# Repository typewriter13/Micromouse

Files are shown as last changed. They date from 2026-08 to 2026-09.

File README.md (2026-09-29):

# Micromouse

MicroMouse is a small autonomous robot designed to navigate and solve a maze completely on its own.
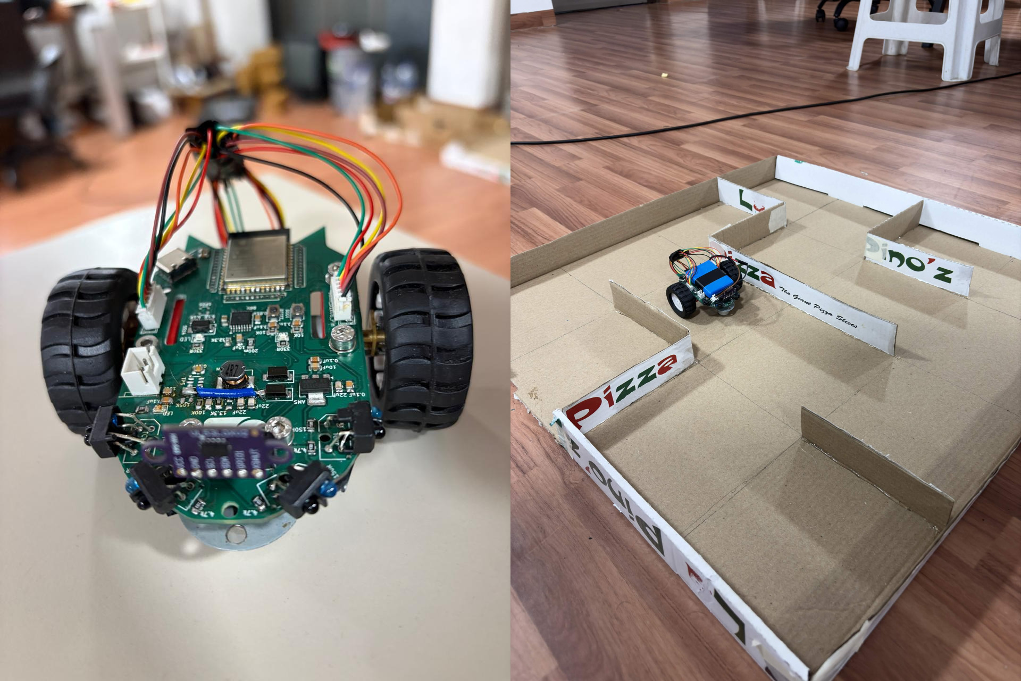
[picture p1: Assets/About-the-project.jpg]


## About The Project

Our project is about a wall-following micromouse robot built on ESP32-S3, using IR proximity sensors for wall-centering and junction detection, a VL53L0X ToF sensor for front-wall stopping, quadrature encoders for wheel feedback, and a WiFi-based web UI for live tuning of PID gains, thresholds, and duty cycle limits.

- <p>
  <a href="https://youtu.be/bc_Xk7g2EeM" target="_blank">
    PCB Moving Demo
  </a>
- <a href="https://youtube.com/shorts/5PlMwJj3upM" target="_blank">
    PCB U-Turn Demo
  </a>
</p>

## Project Overview

### Hardware Used
- 1x ESP32-S3
- 1x DRV8833 Motor Driver
- 1x AMS1117 Buck Converter
- 2x DC encoder Motors
- 4x IR sensors
- 1x VL53L0X (Time of flight sensor)

### Pinout Mapping

| Component | Function / Pin | ESP32-S3 GPIO |
| :--- | :--- | :--- |
| **ToF Sensor** | I2C SDA / SCL | GPIO 41 / GPIO 42 |
| **IR Right (`IR_PIN_0`)** | ADC Input | ADC1 CH2 GPIO 3 |
| **IR Left (`IR_PIN_1`)** | ADC Input | ADC1 CH8 GPIO 9|
| **IR Left Diag (`IR_PIN_2`)** | ADC Input | ADC1 CH9 GPIO 10|
| **IR Right Diag (`IR_PIN_3`)**| ADC Input | ADC1 CH7 GPIO 8|
| **Encoder Motors** | Channel A | GPIO 4 / GPIO 5 |
| **Encoder Motors** | Channel B | GPIO 6 / GPIO 7 |

# Repository Structure

Each subdirectory has its own README with details specific to that piece:

| Directory | Contents |
| :--- | :--- |
| [`LeftWallFollow`](LeftWallFollow/README.md) | Full left-hand-follow navigation, PD wall-centering, ToF stopping, WiFi live tuning |
| [`Test-Codes`](Test-Codes/README.md) | Reference codes for development stages along the project |
| [`PCB`](PCB/README.md) | KiCad schematic and board layout |

## CAD and PCB Models

### PCB Model

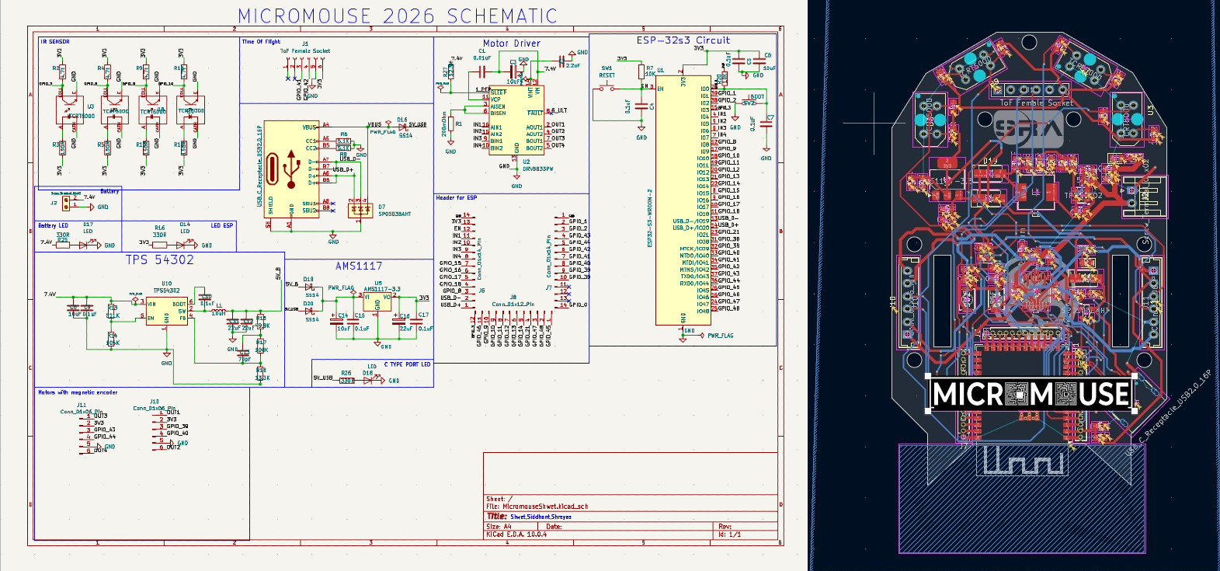
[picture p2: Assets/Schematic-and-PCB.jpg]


### CAD Models

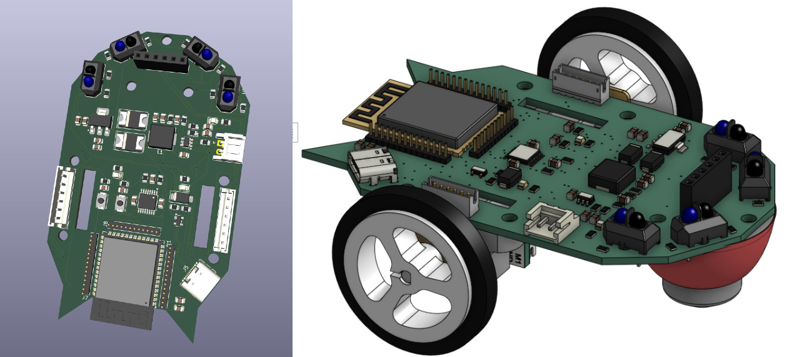
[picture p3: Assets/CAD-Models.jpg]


## Installation and Setup

Prerequisites:
1. ESP-IDF v5.5 
2. Git
3. Python 3.10 or higher

**Setup:**
1. **Clone the Repository**
   ```bash
   git clone https://github.com/typewriter13/Micromouse
   cd Micromouse
   cd LeftWallFollow
2. **Configure and Build**
   ```bash
   idf.py set-target esp32s3
   idf.py build
3. **Flashing the Project**
   ```bash
   idf.py flash monitor

## Future Work

- Implementing Left hand Follow algorithm tuned according to the Maze which we have designed.
- Work and study many more algorithms which are more efficient than LHF.
- Integrate the encoder readings with our path calculations of the bot for mapping the maze and reading the distance travelled.

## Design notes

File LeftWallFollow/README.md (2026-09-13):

# LeftWallFollow

This is the algorithm we have implemented which consists of a logic where the bot follows the adjacent left wall along its entire path finding its way out.

## Project Structure

```
LeftWallFollow/
├── CMakeLists.txt
├── include/
│   ├── ir.h      — IR sensor pin/channel definitions
│   ├── motor.h    — motor GPIO pins, MCPWM function declarations
│   ├── tof.h       — I2C bus config, VL53L0X register addresses
│   └── wifi.h       — tunable-parameters (Kp, Kd, thresholds,
│                       duty limits)
├── main/
│   ├── CMakeLists.txt
│   └── main.c        — app_main(): independent-rate sensor/logic timer,
│                        left-hand-follow, PD wall-centering
└── src/
    ├── ir.c    — ADC oneshot init, channel config
    ├── motor.c  — MCPWM setup, motor run/reverse/brake, turn maneuvers
    ├── tof.c     — I2C init, VL53L0X register read/write, distance calc
    └── wifi.c     — STA WiFi connection, HTTP tuning page
```

## Control Loop

Two independently-timed tasks share one `while(1)` loop, using `esp_timer_get_time()` countdowns rather than a single fixed `vTaskDelay()`:

- **Main logic** (`MAIN_LOGIC_RATE`) — reads all 4 IR channels, runs the left-hand-follow decision, applies PD correction or executes a turn.
- **ToF poll** — reads front distance on its own slower interval, independent of how often the main logic runs.

### Sensor roles

- **ToF sensor** — front-wall brake. Below the configured stop distance, the bot halts and evaluates a turn/U-turn.
- **Front-left / front-right IR** — feed the PD controller for straight-line wall-centering.
- **Diagonal IR (left/right)** — junction detection. Openings must read consistently across several consecutive loop iterations (debounced) before a turn is committed to, filtering single-sample sensor noise.

### Left-hand-follow priority

1. Left diagonal confirms an opening → turn left.
2. Else front is clear (ToF beyond stop distance) → straight, PD-centered.
3. Else right diagonal confirms an opening → turn right.
4. Else (all three blocked) → U-turn.

PD state (`last_error`) is reset immediately after every turn, so the derivative term doesn't react to a stale, pre-turn error value once centering resumes.

### Motor behavior

- **Forward:** both motors, equal duty.
- **Turn left/right:** one wheel at reduced duty, the other at increased duty, for a fixed duration.
- **U-turn:** one motor forward, the other in reverse, for roughly double a single turn's duration.

## Live Tuning over WiFi

On boot the bot joins WiFi and starts an HTTP server. The served page exposes `Kp`, `Kd`, `left_turn_threshold`, `right_turn_threshold`, `wall_distance`, and the duty-cycle limits as live-editable fields — submitting updates the running firmware's `volatile` globals directly, no reflash needed.

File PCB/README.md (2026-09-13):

# PCB

KiCad design for the micromouse's custom PCB

| File | Contents |
| :--- | :--- |
| `MicromouseProject.kicad_pro` | KiCad project file — open this first |
| `MicromouseSch.kicad_sch` | Schematic |
| `MicromousePCB.kicad_pcb` | PCB layout/routing |

Rendered schematic and board images are in [`Assets`](../Assets/) and shown in the [top-level README](../README.md#cad-and-pcb-models).

Requires [KiCad](https://www.kicad.org/) to open and edit.

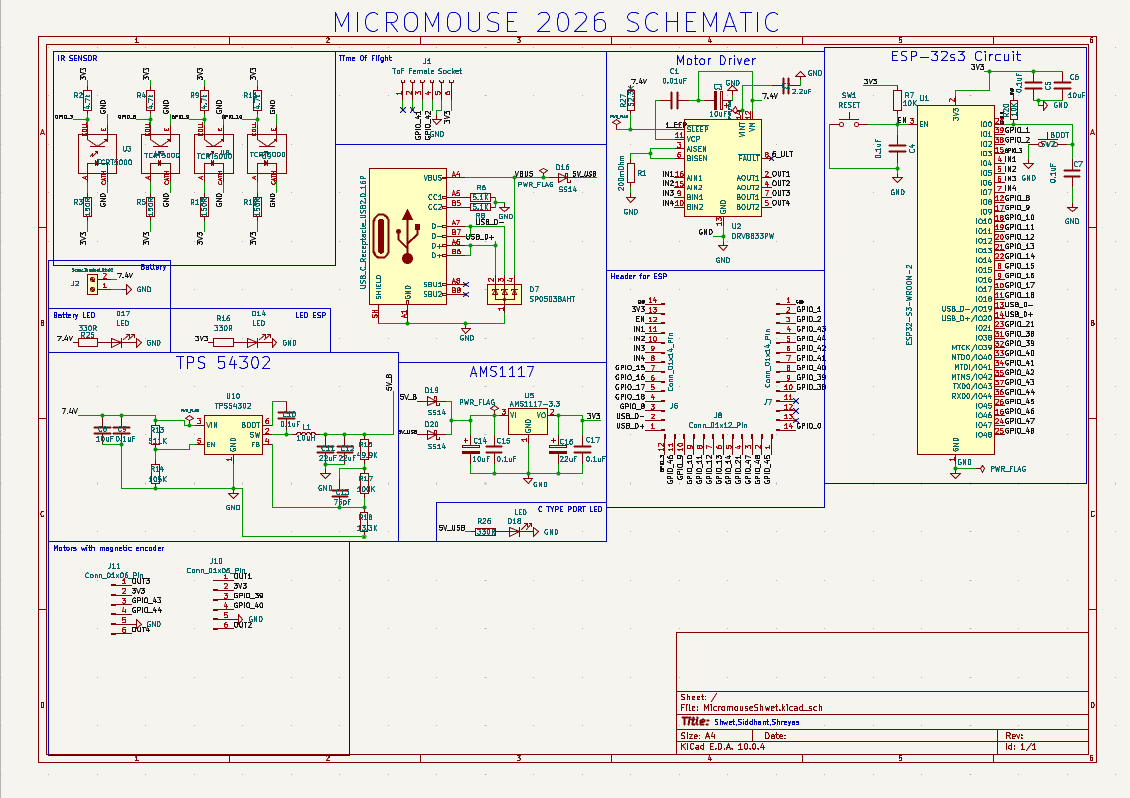
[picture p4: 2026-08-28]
Assets/Schematic.png

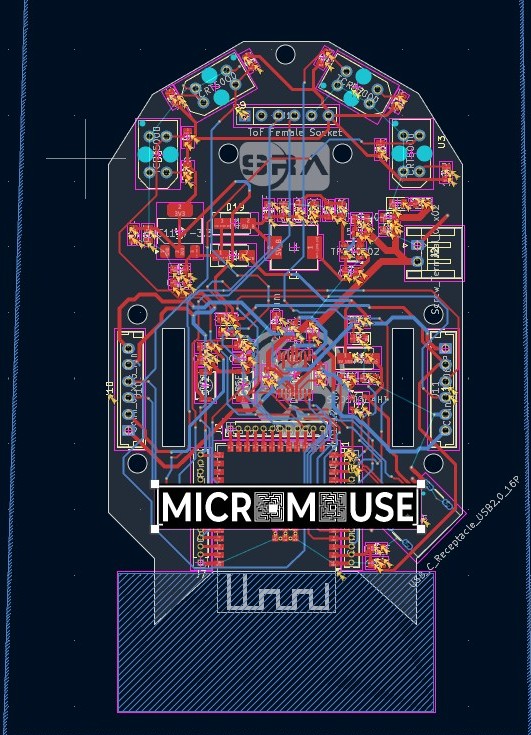
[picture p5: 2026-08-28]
Assets/PCB.jpg

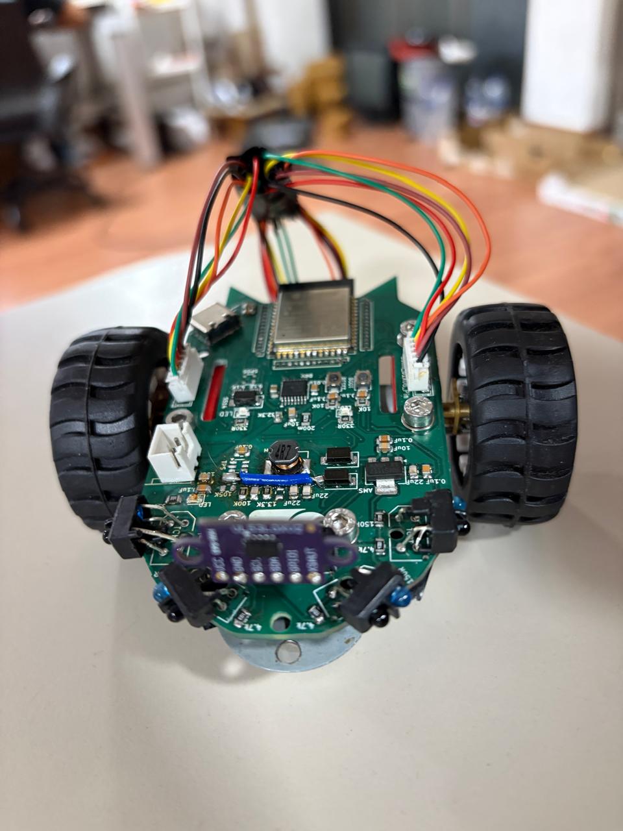
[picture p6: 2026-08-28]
Assets/Micromouse-Closeup.jpg

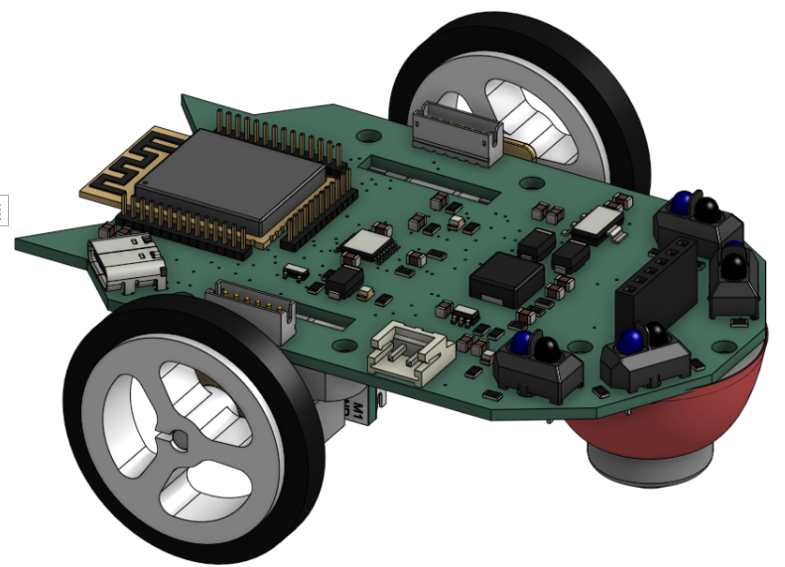
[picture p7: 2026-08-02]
Assets/cadmodelbot.png

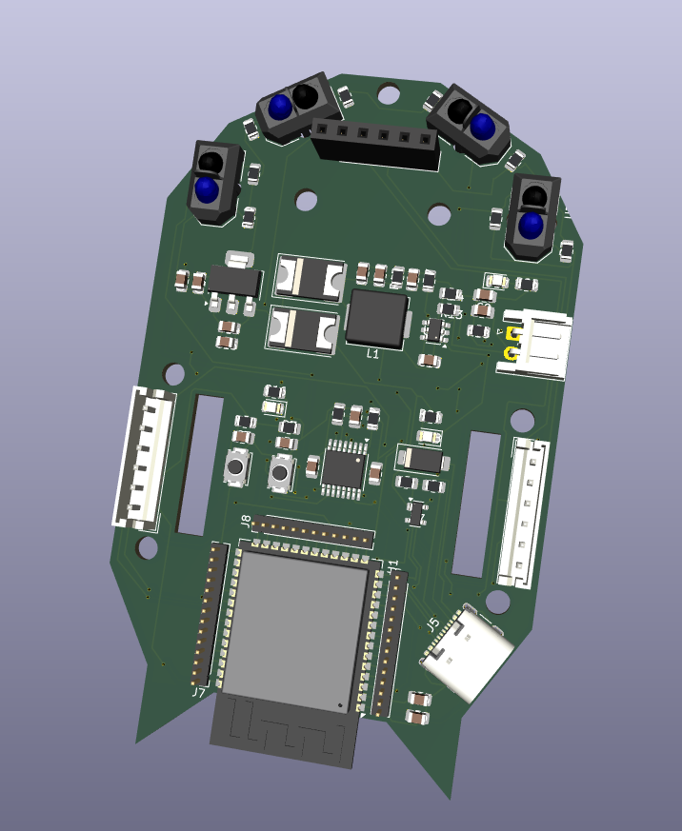
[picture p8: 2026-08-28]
Assets/PCB-CAD-Model.webp

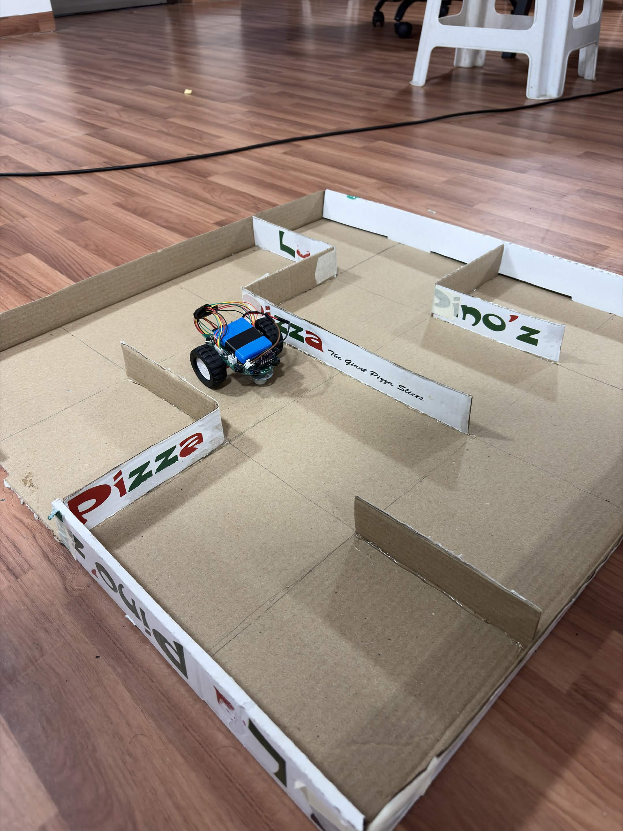
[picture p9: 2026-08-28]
Assets/Micromouse-in-Maze.jpg

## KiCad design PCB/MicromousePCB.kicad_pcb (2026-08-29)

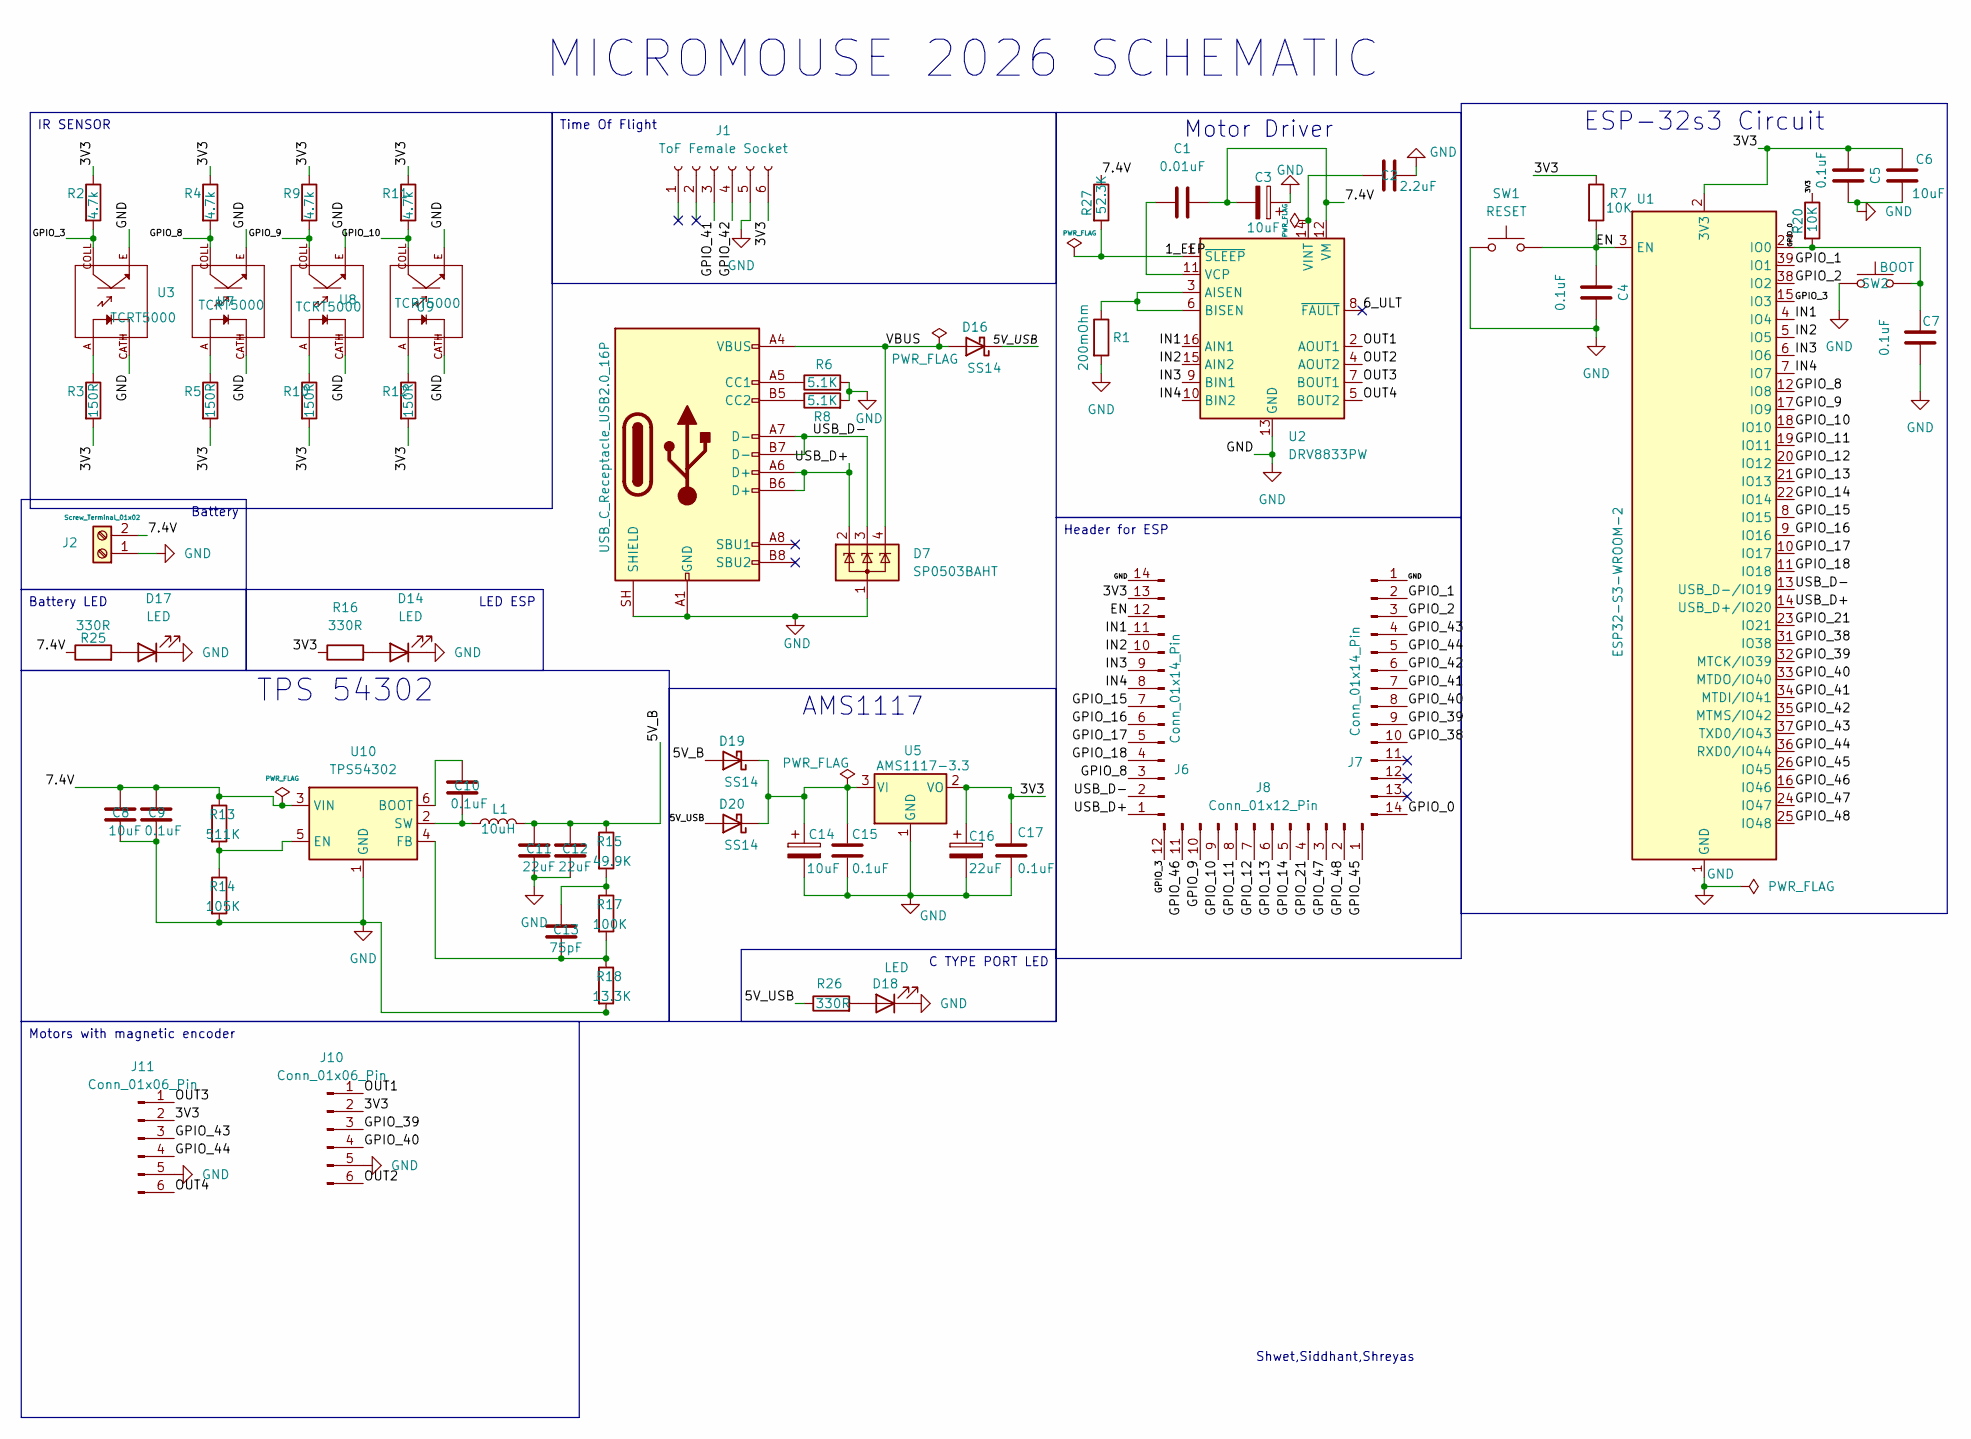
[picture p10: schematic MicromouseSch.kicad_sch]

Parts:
C1: 0.01uF; C_0805_2012Metric
C2: 2.2uF; C_0805_2012Metric
C3, C6, C8, C14: 10uF; C_0805_2012Metric
C4, C5, C7, C9, C10, C15, C17: 0.1uF; C_0805_2012Metric
C11, C12, C16: 22uF; C_0805_2012Metric
C13: 75pF; C_0805_2012Metric
D7: SP0503BAHT; SOT-143
D14, D17, D18: LED; LED_0805_2012Metric
D16, D19, D20: SS14; D_SMA
J1: ToF Female Socket; PinSocket_1x06_P2.54mm_Vertical
J2: Screw_Terminal_01x02; JST_EH_S2B-EH_1x02_P2.50mm_Horizontal
J5: USB_C_Receptacle_USB2.0_16P; USB_C_Receptacle_GCT_USB4105-xx-A_16P_TopMnt_Horizontal
J6, J7: Conn_01x14_Pin; PinHeader_1x14_P1.27mm_Vertical
J8: Conn_01x12_Pin; PinHeader_1x12_P1.27mm_Vertical
J10, J11: Conn_01x06_Pin; JST_ZH_B6B-ZR_1x06_P1.50mm_Vertical
L1: 10uH; L_Sunlord_MWSA0603S
R1: 200mOhm; R_0805_2012Metric
R2, R4, R9, R11: 4.7k; R_0805_2012Metric
R3, R5, R10, R12: 150R; R_0805_2012Metric
R6, R8: 5.1K; R_0805_2012Metric
R7, R20: 10K; R_0805_2012Metric
R13: 511K; R_0805_2012Metric
R14: 105K; R_0805_2012Metric
R15: 49.9K; R_0805_2012Metric
R16, R25, R26: 330R; R_0805_2012Metric
R17: 100K; R_0805_2012Metric
R18: 13.3K; R_0805_2012Metric
R27: 52.3K; R_0805_2012Metric
SW1: RESET; SW_Push_SPST_NO_Alps_SKRK
SW2: BOOT; SW_Push_SPST_NO_Alps_SKRK
U1: ESP32-S3-WROOM-2
U2: DRV8833PW; TSSOP-16_4.4x5mm_P0.65mm
U3, U7, U8, U9: TCRT5000; OPTO_TCRT5000; PARTREV 1.7
U5: AMS1117-3.3; SOT-223-3_TabPin2
U10: TPS54302; SOT-23-6

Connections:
/1_EEP: R27.2, U2.1 (~SLEEP)
/3V3: C5.2, C6.1, C16.1, C17.1, J1.6, J6.13, J10.2, J11.2, R2.1, R3.2, R4.1, R5.2, R7.1, R9.1, R10.2, R11.1, R12.2, R16.1, R20.1, U1.2 (3V3), U5.2 (VO)
/5V_B: C11.1, C12.1, D19.2 (A), L1.2, R15.1
/5V_USB: D16.1 (K), D20.2 (A), R26.1
/6_ULT: U2.8 (~FAULT)
/7.4V: C1.2, C3.2, C8.1, C9.1, J2.2, R13.1, R25.1, R27.1, U2.12 (VM), U10.3 (VIN)
/EN: C4.2, J6.12, R7.2, SW1.2, U1.3 (EN)
/GPIO_0: C7.2, J7.14, R20.2, SW2.2, U1.27 (IO0)
/GPIO_1: J7.2, U1.39 (IO1)
/GPIO_2: J7.3, U1.38 (IO2)
/GPIO_3: J8.12, R2.2, U1.15 (IO3), U3.COLL
/GPIO_8: J6.3, R4.2, U1.12 (IO8), U7.COLL
/GPIO_9: J8.10, R9.2, U1.17 (IO9), U8.COLL
/GPIO_10: J8.9, R11.2, U1.18 (IO10), U9.COLL
/GPIO_11: J8.8, U1.19 (IO11)
/GPIO_12: J8.7, U1.20 (IO12)
/GPIO_13: J8.6, U1.21 (IO13)
/GPIO_14: J8.5, U1.22 (IO14)
/GPIO_15: J6.7, U1.8 (IO15)
/GPIO_16: J6.6, U1.9 (IO16)
/GPIO_17: J6.5, U1.10 (IO17)
/GPIO_18: J6.4, U1.11 (IO18)
/GPIO_21: J8.4, U1.23 (IO21)
/GPIO_38: J7.10, U1.31 (IO38)
/GPIO_39: J7.9, J10.3, U1.32 (MTCK/IO39)
/GPIO_40: J7.8, J10.4, U1.33 (MTDO/IO40)
/GPIO_41: J1.3, J7.7, U1.34 (MTDI/IO41)
/GPIO_42: J1.4, J7.6, U1.35 (MTMS/IO42)
/GPIO_43: J7.4, J11.3, U1.37 (TXD0/IO43)
/GPIO_44: J7.5, J11.4, U1.36 (RXD0/IO44)
/GPIO_45: J8.1, U1.26 (IO45)
/GPIO_46: J8.11, U1.16 (IO46)
/GPIO_47: J8.3, U1.24 (IO47)
/GPIO_48: J8.2, U1.25 (IO48)
/IN1: J6.11, U1.4 (IO4), U2.16 (AIN1)
/IN2: J6.10, U1.5 (IO5), U2.15 (AIN2)
/IN3: J6.9, U1.6 (IO6), U2.9 (BIN1)
/IN4: J6.8, U1.7 (IO7), U2.10 (BIN2)
/OUT1: J10.1, U2.2 (AOUT1)
/OUT2: J10.6, U2.4 (AOUT2)
/OUT3: J11.1, U2.7 (BOUT1)
/OUT4: J11.6, U2.5 (BOUT2)
/USB_D+: D7.2 (K), J5.A6 (D+), J5.B6 (D+), J6.1, U1.14 (USB_D+/IO20)
/USB_D-: D7.3 (K), J5.A7 (D-), J5.B7 (D-), J6.2, U1.13 (USB_D-/IO19)
/VBUS: D7.4 (K), D16.2 (A), J5.A4 (VBUS), J5.A9 (VBUS), J5.B4 (VBUS), J5.B9 (VBUS)
GND: C2.2, C3.1, C4.1, C5.1, C6.2, C7.1, C8.2, C9.2, C11.2, C12.2, C14.2, C15.2, C16.2, C17.2, D7.1 (A), D14.1 (K), D17.1 (K), D18.1 (K), J1.5, J2.1, J5.A1 (GND), J5.A12 (GND), J5.B1 (GND), J5.B12 (GND), J5.SH (SHIELD), J6.14, J7.1, J10.5, J11.5, R1.2, R6.2, R8.2, R14.2, R18.2, SW1.1, SW2.1, U1.1 (GND), U1.40 (GND), U1.41 (GND), U2.13 (GND), U3.CATH, U3.E, U5.1 (GND), U7.CATH, U7.E, U8.CATH, U8.E, U9.CATH, U9.E, U10.1 (GND)
unnamed: C13.1, R15.2, R17.1
unnamed: D14.2 (A), R16.2
unnamed: D17.2 (A), R25.2
unnamed: D18.2 (A), R26.2
unnamed: C14.1, C15.1, D19.1 (K), D20.1 (K), U5.3 (VI)
unnamed: J5.A5 (CC1), R6.1
unnamed: J5.B5 (CC2), R8.1
unnamed: R3.1, U3.A
unnamed: R5.1, U7.A
unnamed: R10.1, U8.A
unnamed: R12.1, U9.A
unnamed: R1.1, U2.3 (AISEN), U2.6 (BISEN)
unnamed: C1.1, U2.11 (VCP)
unnamed: C2.1, U2.14 (VINT)
unnamed: C10.1, U10.6 (BOOT)
unnamed: R13.2, R14.1, U10.5 (EN)
unnamed: C13.2, R17.2, R18.1, U10.4 (FB)
unnamed: C10.2, L1.1, U10.2 (SW)

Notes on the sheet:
MICROMOUSE 2026 SCHEMATIC
Shwet,Siddhant,Shreyas
Motors with magnetic encoder
ESP-32s3 Circuit
LED ESP
IR SENSOR
Battery LED
AMS1117
TPS 54302
Header for ESP
Battery
C TYPE PORT LED
Motor Driver
Time Of Flight

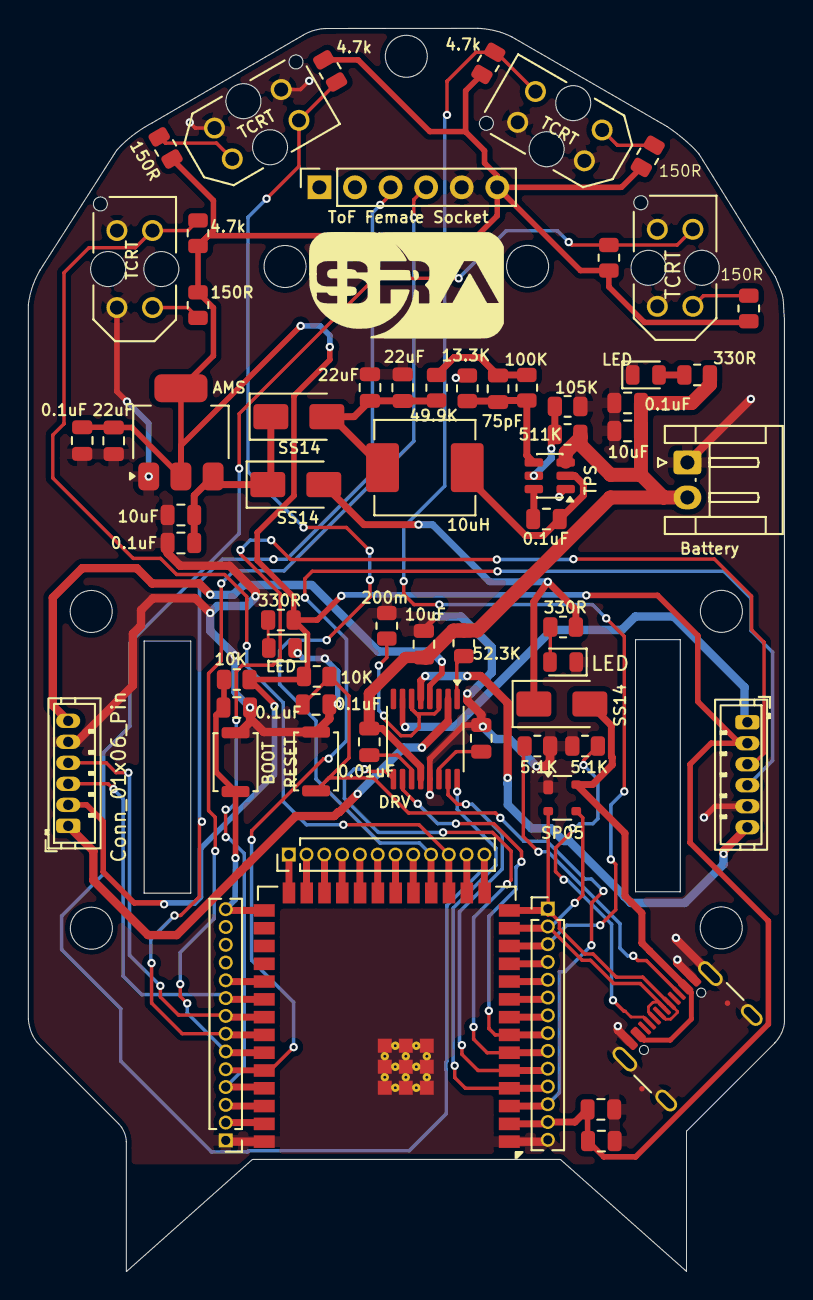
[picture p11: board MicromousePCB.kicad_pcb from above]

Board: 2 copper layers, 54.0 x 88.8 mm, 65 parts (0 on the bottom side), 63 nets.

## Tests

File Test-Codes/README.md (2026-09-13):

# Test Codes

Incremental development stages, kept for reference. Each folder is a standalone ESP-IDF project representing one step on the way to the final firmware in [`LeftWallFollow`](../LeftWallFollow/).

| Folder | What it tests |
| :--- | :--- |
| [`motor`](motor) | Both motors driven straight at a fixed duty, no sensors |
| [`IRtest`](IRtest) | All 4 IR channels read and printed, no motor output |
| [`irmotorcontrol`](irmotorcontrol) | Stop one wheel steering off raw front IR readings |
| [`pid`](pid) | First PD wall-centering + diagonal-based turning, no ToF |
| [`tof-pid`](tof-pid) | PD centering combined with ToF front-wall stopping |

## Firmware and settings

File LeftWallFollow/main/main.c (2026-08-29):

#include <stdio.h>
#include <stdbool.h>
#include "freertos/FreeRTOS.h"
#include "freertos/task.h"
#include "esp_log.h"
#include "nvs_flash.h"
#include "esp_timer.h"

#include "../include/motor.h"
#include "../include/ir.h"
#include "../include/wifi.h"
#include "../include/tof.h"

#define Duty_cycle 18.0
#define JUNCTION_CONFIRM_COUNT 5
#define MAIN_LOGIC_RATE 100


volatile float Kp = 0.008f;
volatile float Kd = 0.0005f;
volatile float max_duty_cycle = 60.0f;
volatile float min_duty_cycle = 10.0f;
volatile int wall_distance = 42;
volatile int left_turn_threshold = 3900;
volatile int right_turn_threshold = 3900;
static float last_error = 0.0f;
static int left_open_count = 0;
static int right_open_count = 0;
static uint16_t distance = 9999;

float correction;

typedef enum {
    bot_brake,
    bot_turn_left,
    bot_turn_right,
    bot_turn_around,
    bot_pd
} Botstate;

float pd_correction(int right_reading, int left_reading, float dt)
{
    float error = (float)(right_reading - left_reading);
    float derivative = (error - last_error) / dt;
    last_error = error;

    float correction = Kp * error + Kd * derivative;
    return correction;
}

void pd_reset()
{
    last_error = 0.0f;
}

void app_main(void)
{
    esp_err_t ret = nvs_flash_init();
    if (ret == ESP_ERR_NVS_NO_FREE_PAGES || ret == ESP_ERR_NVS_NEW_VERSION_FOUND)
    {
        ESP_ERROR_CHECK(nvs_flash_erase());
        ret = nvs_flash_init();
    }
    ESP_ERROR_CHECK(ret);
    wifi_connection();
    start_webserver();
    tof_i2c_init();
    initialize_pwm_gpio_pins();
    pwm_gpio_configuration();
    ir_configuration();

    uint64_t lastMicros = esp_timer_get_time();
    long timer = 0;
    long timerTof = 0;

    while (1)
    {
        uint64_t now = esp_timer_get_time();
        long elapsed = (long)(now - lastMicros);
        lastMicros = now;

        timer -= elapsed;
        timerTof -= elapsed;

        if (timerTof <= 0)
        {
            timerTof = 1000000L / TOF_RATE;
            distance = tof_read_distance();
        }

        if (timer <= 0)
        {
            timer += 1000000L / MAIN_LOGIC_RATE;

            int right_reading = 0, left_reading = 0;
            int left_diag_reading = 0, right_diag_reading = 0;
            float left_motor_duty = 0.0f;
            float right_motor_duty = 0.0f;
            ESP_ERROR_CHECK(adc_oneshot_read(adc1_handle, IR_PIN_0, &right_reading));
            ESP_ERROR_CHECK(adc_oneshot_read(adc1_handle, IR_PIN_1, &left_reading));
            ESP_ERROR_CHECK(adc_oneshot_read(adc1_handle, IR_PIN_2, &left_diag_reading));
            ESP_ERROR_CHECK(adc_oneshot_read(adc1_handle, IR_PIN_3, &right_diag_reading));

            printf("Right: %d  Left: %d  Left Diag: %d  Right Diag: %d ToF: %d\n", right_reading, left_reading, left_diag_reading, right_diag_reading, distance);

            bool left_open = (left_diag_reading > left_turn_threshold);
            bool front_open = (distance > wall_distance);
            bool front_close = (distance < wall_distance);
            bool right_open = (right_diag_reading > right_turn_threshold);

            left_open_count = left_open ? (left_open_count + 1) : 0;
            right_open_count = right_open ? (right_open_count + 1) : 0;
            bool left_confirmed = (left_open_count >= JUNCTION_CONFIRM_COUNT);
            bool right_confirmed = (right_open_count >= JUNCTION_CONFIRM_COUNT);

            Botstate current_state;

            if (left_confirmed)
            {
                current_state = bot_turn_left;
            }
            else if (front_open)
            {
                current_state = bot_pd;
            }
            else if (right_confirmed)
            {
                current_state = bot_turn_right;
            }
            else if (front_close && !right_confirmed && !left_confirmed)
            {
                current_state = bot_turn_around;
            }
            else
            {
                current_state = bot_brake;
            }


            switch (current_state)
            {
            case bot_turn_left:
                turn_left();
                pd_reset();
                break;

            case bot_pd:
            {
                static uint64_t last_pd_time = 0;
                uint64_t pd_now = esp_timer_get_time();

                float actual_dt = (last_pd_time > 0) ? (float)(pd_now - last_pd_time) / 1000000.0f : 0.01f;
                last_pd_time = pd_now;
                correction = pd_correction(right_reading, left_reading, actual_dt);
                left_motor_duty = Duty_cycle + correction;
                right_motor_duty = Duty_cycle - correction;

                if (left_motor_duty > max_duty_cycle)
                    left_motor_duty = max_duty_cycle;
                if (right_motor_duty > max_duty_cycle)
                    right_motor_duty = max_duty_cycle;
                if (left_motor_duty < min_duty_cycle)
                    left_motor_duty = min_duty_cycle;
                if (right_motor_duty < min_duty_cycle)
                    right_motor_duty = min_duty_cycle;

                pwm_left_motor_run(left_motor_duty);
                pwm_right_motor_run(right_motor_duty);
                break;
            }

            case bot_turn_right:
                turn_right();
                pd_reset();
                break;

            case bot_turn_around:

                turn_around();
                pd_reset();
                break;

            case bot_brake:
            default:
                pwm_motors_brake();
            }
        }
        vTaskDelay(pdMS_TO_TICKS(1));
    }
}

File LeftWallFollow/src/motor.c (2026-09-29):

#include "../include/motor.h"

void initialize_pwm_gpio_pins()
{
    mcpwm_gpio_init(MCPWM_UNIT_0, MCPWM0A, MOTOR_PIN_0A);
    mcpwm_gpio_init(MCPWM_UNIT_0, MCPWM0B, MOTOR_PIN_0B);
    mcpwm_gpio_init(MCPWM_UNIT_0, MCPWM1A, MOTOR_PIN_1A);
    mcpwm_gpio_init(MCPWM_UNIT_0, MCPWM1B, MOTOR_PIN_1B);
}

void pwm_gpio_configuration()
{
    mcpwm_config_t pwm_config;
    pwm_config.frequency = 1000;
    pwm_config.cmpr_a = 0;
    pwm_config.cmpr_b = 0;
    pwm_config.counter_mode = MCPWM_UP_COUNTER;
    pwm_config.duty_mode = MCPWM_DUTY_MODE_0;
    mcpwm_init(MCPWM_UNIT_0, MCPWM_TIMER_0, &pwm_config);
    mcpwm_init(MCPWM_UNIT_0, MCPWM_TIMER_1, &pwm_config);
}

void pwm_left_motor_run(float duty_cycle)
{
    mcpwm_set_signal_low(MCPWM_UNIT_0, MCPWM_TIMER_0, MCPWM_OPR_B);
    mcpwm_set_duty(MCPWM_UNIT_0, MCPWM_TIMER_0, MCPWM_OPR_A, duty_cycle);
    mcpwm_set_duty_type(MCPWM_UNIT_0, MCPWM_TIMER_0, MCPWM_OPR_A, MCPWM_DUTY_MODE_0);
}

void pwm_right_motor_run(float duty_cycle)
{
    mcpwm_set_signal_low(MCPWM_UNIT_0, MCPWM_TIMER_1, MCPWM_OPR_B);
    mcpwm_set_duty(MCPWM_UNIT_0, MCPWM_TIMER_1, MCPWM_OPR_A, duty_cycle);
    mcpwm_set_duty_type(MCPWM_UNIT_0, MCPWM_TIMER_1, MCPWM_OPR_A, MCPWM_DUTY_MODE_0);
}

void pwm_left_motor_reverse(float duty_cycle)
{

    mcpwm_set_signal_low(MCPWM_UNIT_0, MCPWM_TIMER_0, MCPWM_OPR_A);
    mcpwm_set_duty(MCPWM_UNIT_0, MCPWM_TIMER_0, MCPWM_OPR_B, duty_cycle);
    mcpwm_set_duty_type(MCPWM_UNIT_0, MCPWM_TIMER_0, MCPWM_OPR_B, MCPWM_DUTY_MODE_0);
}

void pwm_right_motor_reverse(float duty_cycle)
{
    mcpwm_set_signal_low(MCPWM_UNIT_0, MCPWM_TIMER_1, MCPWM_OPR_A);
    mcpwm_set_duty(MCPWM_UNIT_0, MCPWM_TIMER_1, MCPWM_OPR_B, duty_cycle);
    mcpwm_set_duty_type(MCPWM_UNIT_0, MCPWM_TIMER_1, MCPWM_OPR_B, MCPWM_DUTY_MODE_0);
}

void pwm_motors_brake(void)
{
    mcpwm_set_signal_low(MCPWM_UNIT_0, MCPWM_TIMER_0, MCPWM_OPR_A);
    mcpwm_set_signal_low(MCPWM_UNIT_0, MCPWM_TIMER_0, MCPWM_OPR_B);
    mcpwm_set_signal_low(MCPWM_UNIT_0, MCPWM_TIMER_1, MCPWM_OPR_A);
    mcpwm_set_signal_low(MCPWM_UNIT_0, MCPWM_TIMER_1, MCPWM_OPR_B);
}

void turn_left(void)
{
    pwm_left_motor_run(min_duty_cycle);
    pwm_right_motor_run(max_duty_cycle);
    vTaskDelay(10 / portTICK_PERIOD_MS);
    pwm_motors_brake();
}

void turn_right(void)
{
    pwm_left_motor_run(max_duty_cycle);
    pwm_right_motor_run(min_duty_cycle);
    vTaskDelay(10 / portTICK_PERIOD_MS);
    pwm_motors_brake();
}

void turn_around(void)
{
    pwm_right_motor_run(max_duty_cycle);
    pwm_left_motor_reverse(max_duty_cycle);
    vTaskDelay(100 / portTICK_PERIOD_MS);
    pwm_motors_brake();
}

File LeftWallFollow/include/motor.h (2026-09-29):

#include "driver/gpio.h"
#include "freertos/FreeRTOS.h"
#include "freertos/task.h"
#include "esp_attr.h"

#include "driver/mcpwm.h"
#include "soc/mcpwm_periph.h"

#define MOTOR_PIN_0A 4
#define MOTOR_PIN_0B 5
#define MOTOR_PIN_1A 6
#define MOTOR_PIN_1B 7

extern volatile float max_duty_cycle;
extern volatile float min_duty_cycle;

void initialize_pwm_gpio_pins();
void pwm_gpio_configuration();
void pwm_left_motor_run(float duty_cycle);
void pwm_right_motor_run(float duty_cycle);
void pwm_left_motor_reverse(float duty_cycle);
void pwm_right_motor_reverse(float duty_cycle);
void turn_around(void);
void turn_right(void);
void turn_left(void);
void pwm_motors_brake(void);

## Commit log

2026-08-02 corrected the naming of folders
    [main.c]
2026-08-29 add: test codes and PCB
    [MicromousePCB.kicad_pcb, MicromouseSch.kicad_sch]
